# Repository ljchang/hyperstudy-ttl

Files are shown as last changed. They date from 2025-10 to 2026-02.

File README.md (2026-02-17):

# HyperStudy TTL

RP2040-based TTL pulse generator for HyperStudy experiments with electrical isolation via optocoupler.

## Architecture

```
HyperStudy TriggerComponent → hyperstudy-bridge → RP2040 (this firmware) → TTL Output
```

This repository contains the **RP2040 firmware** that receives trigger commands from [hyperstudy-bridge](https://github.com/cosanlab/hyperstudy-bridge) and generates electrically-isolated TTL pulses (configurable duration, default 10ms) for external equipment.

## Features

- **Fast & Reliable:** <1ms latency via USB serial communication
- **Electrical Isolation:** HCPL-2211 optocoupler protects both devices
- **Bridge Compatible:** Response format matches hyperstudy-bridge parser expectations
- **Easy Setup:** PlatformIO-based firmware with comprehensive installation docs

## Quick Start

### 1. Install Firmware

```bash
cd firmware
pio run --target upload
```

### 2. Test Connection

```bash
pio device monitor
```

Type `PULSE` and press Enter. The device should respond with `OK:Pulse sent`. Each device reports its unique serial number on startup.

### 3. Full Setup

See **[INSTALLATION.md](./INSTALLATION.md)** for complete instructions including:
- Hardware assembly and optocoupler wiring
- Bridge integration and configuration
- TriggerComponent setup in HyperStudy
- Troubleshooting guide

## Hardware

- **Microcontroller:** Adafruit Feather RP2040
- **Optocoupler:** HCPL-2211 (for isolation)
- **Pulse Output:** GPIO Pin 6 / D4 (configurable duration, default 10ms HIGH pulse)
- **Communication:** USB serial, 115200 baud
- **USB Identification:** VID: `0x239A`, PID: `0x80F1`

See [OPTOCOUPLER_WIRING.md](./OPTOCOUPLER_WIRING.md) for detailed wiring instructions.

## Commands

The firmware accepts case-insensitive serial commands:

| Command | Response | Description |
|---|---|---|
| `PULSE` | `OK:Pulse sent` | Triggers TTL pulse (default duration) |
| `PULSE <ms>` | `OK:Pulse sent` | Triggers TTL pulse with specified duration |
| `SETDURATION <ms>` | `OK:Duration set to <ms>ms` | Sets default pulse duration (1-10000ms) |
| `TIMING` | `OK:Timing us:<N>,dur:<ms>` | Reports last pulse timing (serial-to-GPIO, µs) |
| `TEST` | `OK:Test successful` | Connection validation |
| `VERSION` | `OK:Version 1.4.0` | Firmware version query |
| `SERIAL` | `OK:Serial <hex>` | Reports unique board serial number |
| `LONGPULSE` | `OK:Long pulse sent` | Triggers 3-second pulse for testing |

## Device Discovery

The device can be reliably found by USB VID/PID, regardless of which port macOS assigns:

```python
# Find device by VID/PID (works with any HyperStudy TTL device)
python3 testing/find_ttl_port.py
```

This returns the current port path (e.g., `/dev/cu.usbmodem2101`).

## Alternative Implementations

Alternative firmwares (Arduino IDE, CircuitPython) are provided in `/examples` for reference but are **not recommended** for production use as they may not be fully compatible with hyperstudy-bridge.

## Documentation

- **[INSTALLATION.md](./INSTALLATION.md)** - Complete setup guide with bridge integration
- **[OPTOCOUPLER_WIRING.md](./OPTOCOUPLER_WIRING.md)** - Detailed optocoupler wiring instructions
- **[CLAUDE.md](./CLAUDE.md)** - Developer notes and architecture details

## Support

For detailed user documentation on using TTL triggers in HyperStudy experiments, see the [HyperStudy documentation](https://github.com/cosanlab/hyperstudy).

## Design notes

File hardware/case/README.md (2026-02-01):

# HyperStudy TTL Case

3D printable enclosure for the HyperStudy TTL FeatherWing + Adafruit Feather RP2040 stack.

## Files

| File | Description |
|---|---|
| `hyperstudy-ttl-case.scad` | OpenSCAD parametric design source |
| `bottom.stl` | Bottom shell (generate from OpenSCAD) |
| `top.stl` | Top shell (generate from OpenSCAD) |

## Generating STL Files

1. Install [OpenSCAD](https://openscad.org/downloads.html)
2. Open `hyperstudy-ttl-case.scad`
3. For bottom shell:
   - Comment out assembly view at bottom
   - Uncomment `bottom_shell();`
   - Render (F6) and Export as STL
4. For top shell:
   - Comment out `bottom_shell();`
   - Uncomment `top_shell();`
   - Render (F6) and Export as STL

## Printing Recommendations

### Material
- **PLA**: Easy to print, good for most uses
- **PETG**: Better heat resistance and durability
- **ABS**: Best durability, requires enclosure

### Settings (Bambu Studio / PrusaSlicer)
| Parameter | Recommended | Notes |
|---|---|---|
| Layer height | 0.20mm | 0.16mm for finer detail |
| Walls | 4 perimeters | Strength at screw holes |
| Top/Bottom | 5 layers | Prevents flex |
| Infill | 15% gyroid | Good strength-to-weight |
| Supports | Not required | Designed for supportless printing |
| Brim | 5mm (first print) | Helps bed adhesion |

### Print Orientation (Critical)
- **Bottom shell**: Print as exported (floor on print bed)
- **Top shell**: Flip upside down in slicer (ceiling on print bed, open side facing up)

### Print Time (Bambu P1/X1 estimated)
- Bottom shell: ~45min - 1 hour
- Top shell: ~1 - 1.5 hours

## Hardware Required

| Item | Quantity | Notes |
|---|---|---|
| M2 x 35mm pan head screws | 4 | Through top shell, PCB, standoffs |
| M2 hex nuts | 4 | Press into hex pockets on bottom exterior |
| Rubber feet (optional) | 4 | ~10mm diameter adhesive feet |

## Assembly

1. **Prepare the PCB stack**
   - Solder all components to FeatherWing
   - Stack FeatherWing onto Feather RP2040 via headers

2. **Install M2 nuts in bottom shell**
   - Press M2 hex nuts into the 4 hex pockets on the exterior bottom
   - Nuts should sit flush or slightly recessed

3. **Install PCB in bottom shell**
   - Place assembled PCB stack onto the 4 standoffs
   - PCB mounting holes align with standoff holes
   - USB port aligns with cutout on short end
   - BNC connector faces opposite end

4. **Attach top shell**
   - Place top shell over assembly
   - Interlocking lip on bottom shell fits inside top shell cavity (3 sides)
   - BNC connector protrudes through cutout
   - Screw holes align at all 4 corners

5. **Secure with screws**
   - Insert M2x35mm screws through counterbored holes in top shell
   - Screws pass through: top shell ceiling > PCB > standoffs > floor > nuts
   - Tighten snugly (don't overtighten - plastic threads)

6. **Add rubber feet (optional)**
   - Apply adhesive rubber feet to bottom exterior

## Design Features

### Interlocking Lip
The bottom shell has a 1.5mm tall lip that extends into the top shell on three sides (USB end and both long sides). The BNC end is open to accommodate the panel-mount connector. This provides:
- Lateral alignment between shells
- Prevents shifting during use
- 0.3mm clearance for FDM printing tolerances

### PCB Support
The top shell includes internal ribs that press down on the PCB edges, securing it in place when assembled.

## Customization

The OpenSCAD file is fully parametric. Key parameters to adjust:

```scad
/* Fit adjustments */
pcb_clearance = 1.5;          // Clearance around PCB edges (mm)
lip_clearance = 0.3;          // Gap between interlocking lip and top shell (mm)

/* Structural */
wall = 2.5;                   // Wall thickness (mm)
floor_thickness = 6;          // Bottom shell floor (mm)
ceiling_thickness = 3.5;      // Top shell ceiling (mm)

/* Component clearance */
component_height_top = 19.6;  // Height above PCB for Feather + headers (mm)
component_height_bottom = 5;  // Height below PCB for BNC/solder joints (mm)

/* Connector cutouts */
bnc_diameter = 13;            // BNC hole diameter (mm)
usb_width = 10;               // USB-C port width (mm)
usb_height = 4;               // USB-C port height (mm)
```

## Dimensions

| Dimension | Value |
|---|---|
| Case length | ~93mm |
| Case width | ~43mm |
| Case height (assembled) | ~36mm |
| Bottom shell height | 11mm |
| Top shell height | 24.7mm |
| Wall thickness | 2.5mm |

## Troubleshooting

### Fit Issues
| Symptom | Likely Cause | Fix |
|---|---|-----|
| PCB won't seat flat | Standoffs too tall | Reduce `standoff_height` |
| Shells won't close | PCB sitting too high | Verify `standoff_height = component_height_bottom` |
| Top shell shifts laterally | Lip clearance too large | Reduce `lip_clearance` |
| Lip won't fit in top shell | Lip clearance too small | Increase `lip_clearance` to 0.4mm |
| USB cable won't insert | Cutout too small | Increase `usb_width` or `usb_height` |
| BNC nut won't thread | Hole too small | Increase `bnc_diameter` |

### Print Quality Issues
| Symptom | Likely Cause | Fix |
|---|---|-----|
| Stringing at cutouts | Retraction settings | Increase retraction, enable wipe |
| Hex pockets too tight | FDM shrinkage | Increase `nut_width` parameter |
| Screw holes too tight | FDM shrinkage | Increase `screw_hole_diameter` |
| Warped corners | Bed adhesion | Add brim, increase bed temp |

### Measurement Tips
1. Use calipers - don't eyeball tolerances
2. Measure printed parts - actual dimensions often differ from CAD by +/-0.2mm
3. Test fit components before final assembly
4. If holes are slightly tight, an M2 drill bit can clean them up

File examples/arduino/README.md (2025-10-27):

# Arduino IDE Example

This is an alternative firmware implementation using the Arduino IDE.

**Note:** This is provided as an example only. The **recommended** firmware is in `/firmware` (PlatformIO).

## Compatibility Notes

- Uses emoji in responses (not parsed by hyperstudy-bridge)
- Different pin logic than primary firmware
- Easier for beginners to modify without PlatformIO

## Usage

1. Open `arduino_sketch_hyperstudyttl.ino` in Arduino IDE
2. Install Adafruit TinyUSB library
3. Select "Adafruit Feather RP2040" board
4. Upload to device

## Limitations

- Response format not fully compatible with hyperstudy-bridge parsing
- May require bridge code modifications to work correctly

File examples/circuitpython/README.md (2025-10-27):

# CircuitPython Example

This is an alternative firmware implementation using CircuitPython.

**Note:** This is provided as an example only. The **recommended** firmware is in `/firmware` (PlatformIO).

## Compatibility Notes

- Python-based, no compilation needed
- Slower response time than C++ implementations
- Easier to debug and modify on-device
- Response format has extra space: `"OK: Pulse Triggered!\n"` (may not parse correctly in bridge)

## Usage

1. Install CircuitPython on your Feather RP2040
2. Copy `code.py` to the CIRCUITPY drive
3. Device will auto-restart with new code

## Configuration

You may need to create `settings.toml` on CIRCUITPY for WebUSB origin configuration:

```toml
CIRCUITPY_USB_VENDOR = 0x239A
CIRCUITPY_USB_PRODUCT = 0x80F1
```

## Limitations

- Response format not fully compatible with hyperstudy-bridge parsing
- Slightly higher latency than compiled C++ firmware
- Requires CircuitPython 9+ for WebUSB support

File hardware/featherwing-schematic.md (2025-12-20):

# HyperStudy TTL FeatherWing Schematic

This document describes the schematic design for a FeatherWing add-on board that provides electrically-isolated TTL output from an Adafruit Feather RP2040.

## Design Overview

The FeatherWing provides:
- HCPL-2211 optocoupler for galvanic isolation
- Isolated 5V power supply (B0505S-1W DC-DC isolator)
- BNC output connector for TTL signal
- All necessary bypass capacitors and current limiting resistors

## Schematic Block Diagram

```
┌─────────────────────────────────────────────────────────────────────────────┐
│                         HyperStudy TTL FeatherWing                          │
├─────────────────────────────────────────────────────────────────────────────┤
│                                                                             │
│   Feather                                                                   │
│   Header         Input Stage           Isolation          Output Stage     │
│                                                                             │
│   D4 (GP6) ──────[220Ω]──────┐                                             │
│                               │      HCPL-2211                              │
│                               ├─────┤2 (A)  8├───────────┬──── +5V ISO     │
│                               │     │        │           │                  │
│   GND ────────────────────────┴─────┤3 (K)  7├──[47Ω]────┼───► BNC+        │
│                                     │        │           │                  │
│                              NC ────┤1      6├── NC      │                  │
│                                     │        │           │                  │
│                              NC ────┤4      5├───────────┼──── GND ISO     │
│                                     └────────┘           │      │          │
│                                                   [0.1µF]│    [BNC-]       │
│                                                          │                  │
│                                                          └──────────────────┤
│   USB 5V ─────┬─────[0.1µF]─────┬─────────────────────────────────────────┤
│               │                 │         B0505S-1W                        │
│               │                 │        ┌─────────┐                       │
│               └─────────────────┼────────┤+Vin Vout+├───────► +5V ISO     │
│                                 │        │         │                       │
│   GND ──────────────────────────┼────────┤-Vin Vout-├───────► GND ISO     │
│                                 │        └─────────┘     │                 │
│                              [10µF]                   [10µF]               │
│                                 │                        │                 │
│                                GND                    GND ISO              │
│                                                                             │
└─────────────────────────────────────────────────────────────────────────────┘
```

## Component List

### Semiconductors
| Ref | Component | Value | Package | Notes |
|-----|---|---|---|---|
| U1 | HCPL-2211 | - | DIP-8 | Totem pole optocoupler |
| U2 | B0505S-1W | 5V→5V | SIP-4 | 1W isolated DC-DC converter |

### Resistors
| Ref | Value | Package | Tolerance | Notes |
|-----|---|---|---|---|
| R1 | 220Ω | 0805 | 5% | LED current limiting (8mA) |
| R2 | 47Ω | 0805 | 5% | BNC impedance matching |

### Capacitors
| Ref | Value | Package | Voltage | Notes |
|-----|---|---|---|---|
| C1 | 0.1µF | 0805 | 16V | DC isolator input filter |
| C2 | 10µF | Electrolytic | 16V | DC isolator input bulk |
| C3 | 0.1µF | 0805 | 16V | Optocoupler bypass (Pin 5-8) |
| C4 | 10µF | Electrolytic | 16V | Optocoupler output bulk |

### Connectors
| Ref | Component | Notes |
|-----|---|---|
| J1 | Feather Header (16-pin) | Left side of Feather |
| J2 | Feather Header (12-pin) | Right side of Feather |
| J3 | BNC Female | Panel mount or PCB mount |

## Feather Header Pinout (Relevant Pins)

### Left Header (J1 - 16 pins, top to bottom)
```
Pin  Name    Use
1    RST     -
2    3V3     -
3    AREF    -
4    GND     Optocoupler cathode (Pin 3)
5    A0      -
6    A1      -
7    A2      -
8    A3      -
9    24      -
10   25      -
11   SCK     -
12   MOSI    -
13   MISO    -
14   RX      -
15   TX      -
16   D4      → TTL Trigger (GP6)
```

### Right Header (J2 - 12 pins, top to bottom)
```
Pin  Name    Use
1    VBAT    -
2    EN      -
3    VBUS    USB 5V → DC isolator input
4    D13     -
5    D12     -
6    D11     -
7    D10     -
8    D9      -
9    D6      -
10   D5      -
11   SCL     -
12   SDA     -
```

## Schematic Connections

### Input Stage (Non-Isolated)
1. **D4 (GP6)** → R1 (220Ω) → U1 Pin 2 (Anode)
2. **GND** → U1 Pin 3 (Cathode)
3. **VBUS** → C1 (0.1µF) → GND
4. **VBUS** → C2 (10µF +) → GND
5. **VBUS** → U2 Pin 1 (+Vin)
6. **GND** → U2 Pin 2 (-Vin)

### Output Stage (Isolated)
1. **U2 Pin 4 (+Vout)** → U1 Pin 8 (VCC)
2. **U2 Pin 3 (-Vout)** → U1 Pin 5 (GND)
3. **U1 Pin 5** → C3 (0.1µF) → U1 Pin 8
4. **U1 Pin 5** → C4 (10µF -), C4 (+) → U1 Pin 8
5. **U1 Pin 7 (VO)** → R2 (47Ω) → J3 BNC Center
6. **U1 Pin 5 (GND)** → J3 BNC Shield
7. **U1 Pin 1, 4, 6** → NC (No Connection)

## Design Notes

### Isolation Barrier
- The dashed line in the block diagram represents the isolation barrier
- Input ground (Feather GND) and output ground (ISO GND) must be kept separate
- The B0505S-1W provides 1kV isolation between input and output

### Component Placement
- Place C3 (bypass cap) as close to U1 pins 5 and 8 as possible
- Keep the input stage components grouped on one side of the board
- Keep the output stage components grouped on the other side
- Maintain creepage distance across isolation barrier (min 2mm recommended)

### Totem Pole Output
- The HCPL-2211 has an active push-pull output
- No pull-up resistor is needed
- Output can source/sink ~25mA

### Signal Integrity
- R2 (47Ω) provides approximate 50Ω impedance matching for BNC cable
- Keep traces to BNC connector short and direct

## EasyEDA Import Instructions

1. Open EasyEDA (https://easyeda.com)
2. Create a new project: File → New → Project
3. Create a new schematic: File → New → Schematic
4. Import components from LCSC (EasyEDA's parts library):
   - Search for each component by part number
   - Add to schematic
5. Wire components according to the connections above
6. Convert to PCB: Design → Convert to PCB
7. Arrange components on the PCB
8. Route traces (auto-route or manual)
9. Add ground planes if desired
10. Run DRC (Design Rule Check)
11. Generate Gerber files for fabrication

## Bill of Materials (BOM)

| Qty | Component | Value | LCSC Part # | Notes |
|-----|---|---|---|---|
| 1 | HCPL-2211 | - | C6933 | DIP-8 optocoupler |
| 1 | B0505S-1W | 5V | C87025 | DC-DC isolator |
| 1 | Resistor | 220Ω | C17557 | 0805, 5% |
| 1 | Resistor | 47Ω | C17714 | 0805, 5% |
| 2 | Capacitor | 0.1µF | C49678 | 0805 ceramic |
| 2 | Capacitor | 10µF | C19702 | Electrolytic 16V |
| 1 | BNC Connector | Female | C496553 | PCB mount |
| 1 | Pin Header | 1x16 2.54mm | C2337 | Female for Feather |
| 1 | Pin Header | 1x12 2.54mm | C2334 | Female for Feather |

Note: LCSC part numbers are examples. Verify availability and specifications before ordering.

## FeatherWing Dimensions

Standard FeatherWing dimensions:
- Width: 22.86mm (0.9")
- Length: 50.8mm (2.0")
- Mounting holes: Match Feather pattern

The BNC connector will extend beyond the standard FeatherWing footprint.
Consider using a right-angle BNC or panel-mount BNC with wires.

## Testing After Assembly

1. Power on with Feather RP2040 attached
2. Measure isolated 5V output (should read 4.1-5.0V)
3. Connect multimeter to BNC output
4. Idle voltage should be ~0.3V (LOW)
5. Send PULSE command via serial
6. Pulse voltage should reach ~3.9V (HIGH)

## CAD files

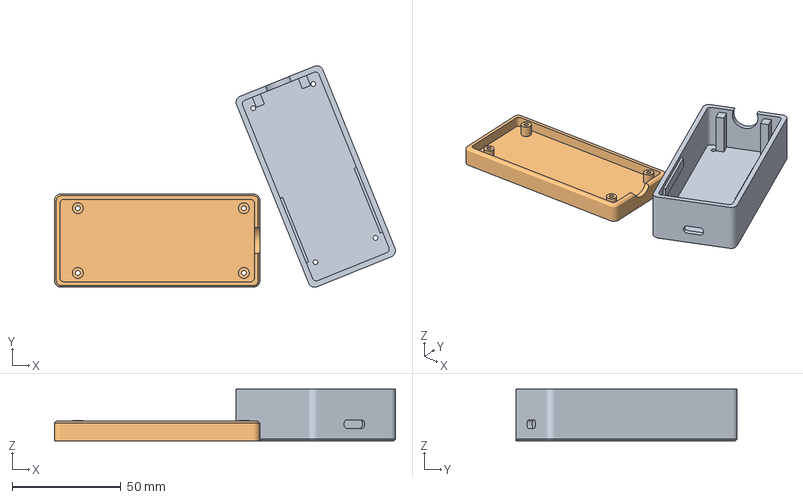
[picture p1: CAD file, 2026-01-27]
hardware/case/hyperstudy-ttl-case.3mf
156.5 x 101.7 x 23.7 mm
hyperstudy-ttl-case.stl_2
hyperstudy-ttl-case.stl_1

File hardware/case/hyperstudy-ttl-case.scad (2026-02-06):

// HyperStudy TTL FeatherWing Case
// Parametric design for 3D printing
//
// Usage:
//   - Render bottom_shell() and export as bottom.stl
//   - Render top_shell() and export as top.stl
//   - Print orientation (IMPORTANT):
//       * Bottom shell: Print as exported (floor on bed)
//       * Top shell: FLIP UPSIDE DOWN in slicer (ceiling on bed, open side up)
//   - Insert M2 nuts into hex pockets on bottom shell exterior
//   - Assemble with 4x M2x35mm pan head screws through top shell, PCB, standoffs, into nuts

/* [PCB Dimensions] */
// FeatherWing v1.1 PCB length (mm)
pcb_length = 81.30;
// FeatherWing v1.1 PCB width (mm)
pcb_width = 34.80;
// PCB thickness (mm)
pcb_thickness = 1.6;
// BNC connector extension past board edge (mm) - set to 0 so BNC protrudes outside case
bnc_extension = 0;
// Feather overhang past FeatherWing on USB end (mm)
feather_extension = 3.5;

/* [Component Heights] */
// Height above FeatherWing PCB for Feather RP2040 + headers (measured: 19.6mm to top)
component_height_top = 19.6;
// Height below FeatherWing PCB for BNC/solder joints (measured: 4.75mm lowest point)
component_height_bottom = 5;

/* [Case Parameters] */
// Wall thickness (mm)
wall = 2.5;
// Floor thickness (mm) - 7mm for solid bridging over nut pockets (4.5mm solid above pocket)
floor_thickness = 7;
// Top shell ceiling thickness (mm) - needs enough material for counterbore + shaft shelf
// For M2 pan head: 2mm counterbore + 2.5mm shelf = 4.5mm minimum
ceiling_thickness = 4.5;
// PCB clearance on each side (mm) - increased to accommodate support ribs
pcb_clearance = 1.5;
// Corner radius (mm)
corner_radius = 3;
// External edge chamfer for clean printing (mm)
edge_chamfer = 0.8;

/* [Screw Parameters] */
// M2 screw clearance hole diameter (mm) - oversized for FDM shrinkage
screw_hole_diameter = 2.6;
// M2 nut width across flats (mm) - actual is 4.0mm, add 0.7mm for FDM shrinkage
nut_width = 4.7;
// M2 nut pocket depth (mm) - actual nut is 1.6mm, extra depth for capture and clearance
nut_pocket_depth = 2.5;
// M2 pan head counterbore diameter (mm) - head is ~4mm, add tolerance
counterbore_diameter = 4.5;
// M2 pan head counterbore depth (mm) - head is ~2mm, flush fit
counterbore_depth = 2.0;

/* [Connector Cutouts] */
// USB-C port width (mm)
usb_width = 10;
// USB-C port height (mm)
usb_height = 4;
// USB-C corner radius for printability and aesthetics (mm)
usb_corner_radius = 1.5;
// USB port vertical offset from shell interface (mm) - adjusted +4.2mm from original calibration
usb_offset_z = 14.05;
// USB port horizontal offset from center (mm)
usb_offset_y = 0;
// BNC connector diameter (mm) - panel-mount requires ~12.5mm clearance (+0.5mm tolerance)
bnc_diameter = 13;
// BNC connector vertical offset from shell interface (mm) - positive moves hole up
bnc_offset_z = 2.65;

/* [PCB Support Ribs] */
// Enable PCB edge support ribs in top shell
pcb_supports_enabled = true;
// Rib width (mm) - extends from wall over PCB edge, pressing down on PCB surface
pcb_support_width = 4;
// Ribs extend from pcb_rail_z_offset to ceiling (matching BNC corner posts)

// Rail positioning - runs along Feather section only (avoids FeatherWing components)
// Start after USB-side screw holes, run along where Feather sits
pcb_rail_start = 12;              // Start X position (mm from USB end wall, after screw holes)
pcb_rail_length = 32;             // Length of rail (mm) - covers Feather area
// Z offset = PCB thickness + clearance, so rails are above PCB when it sits flush/inset
pcb_rail_z_offset = pcb_thickness + 0.5;  // 1.6 + 0.5 = 2.1mm from open edge

// BNC-side corner posts (between BNC cutout and screw holes)
bnc_posts_enabled = true;
bnc_post_diameter = 4;            // Post diameter (mm)
bnc_post_height = 4;              // Post height (mm)
bnc_post_inset_x = 5;             // Post X inset from BNC end wall (mm)
bnc_post_inset_y = 10;            // Post Y inset from case side walls (mm)

/* [Logo] */
// Logo scale factor (0.07 = large, may extend to edges)
logo_scale = 0.07;
// Logo emboss depth (mm)
logo_depth = 0.8;
// Logo X offset from center (mm)
logo_offset_x = 0;
// Logo Y offset from center (mm)
logo_offset_y = 22;
// Logo rotation (degrees)
logo_rotation = 90;

/* [Rendering] */
// Resolution for curved surfaces
$fn = 50;

// Calculated dimensions
case_inner_length = pcb_length + 2 * pcb_clearance + feather_extension;
case_inner_width = pcb_width + 2 * pcb_clearance;
case_outer_length = case_inner_length + 2 * wall;
case_outer_width = case_inner_width + 2 * wall;
case_height_bottom = component_height_bottom + floor_thickness;
case_height_top = component_height_top + ceiling_thickness + pcb_thickness;
total_case_length = case_outer_length + bnc_extension;

// PCB ledge parameters
pcb_ledge_height = 2;
pcb_ledge_width = 1.5;

// FeatherWing v1.1 mounting hole positions (from PCB corner)
// 4x M2 mounting holes extracted from Gerber drill file
fw_hole_inset_x = 2.54;           // Hole inset from left/right edges
fw_hole_inset_y = 2.54;           // Hole inset from bottom/top edges
fw_hole_spacing_x = 76.2;         // Horizontal spacing between holes
fw_hole_spacing_y = 29.72;        // Vertical spacing between holes
fw_hole_diameter = 2.032;         // M2 clearance holes in PCB

// Standoff parameters (sized for M2 screws)
standoff_diameter = 5;
standoff_hole_diameter = 2.6;     // M2 clearance hole - oversized for FDM shrinkage
standoff_height = component_height_bottom;  // Height to support PCB at shell interface
pcb_bnc_offset = 0.8;             // Extra clearance between PCB/standoffs and BNC end (mm)

/* [Shell Interlocking] */
// Lip height extending above bottom shell edge (mm)
// Must be less than pcb_rail_z_offset to clear top shell support ribs
lip_height = 1.5;
// Lip wall thickness (mm) - reduced from 1.5 to provide 0.3mm clearance to PCB edge
lip_thickness = 1.2;
// Clearance between lip and top shell inner wall (mm)
lip_clearance = 0.3;

// Module: Interlocking lip for bottom shell (excludes BNC end)
// Creates a thin wall rising from the inner perimeter to fit inside top shell
module interlocking_lip() {
    // Inner dimensions where lip attaches (flush with cavity wall for printability)
    // lip_clearance is applied to the TOP shell's cavity, not here
    inner_x_start = wall;
    inner_x_end = wall + case_inner_length - lip_clearance;  // Stop before BNC extension
    inner_y_start = wall;
    inner_y_end = wall + case_inner_width;
    inner_radius = corner_radius - wall/2;

    // Lip rises from top of bottom shell
    translate([0, 0, case_height_bottom]) {
        difference() {
            // Outer boundary of lip (flush with cavity walls for printability)
            hull() {
                for (x = [inner_x_start + inner_radius, inner_x_end - inner_radius]) {
                    for (y = [inner_y_start + inner_radius, inner_y_end - inner_radius]) {
                        translate([x, y, 0])
                            cylinder(r = inner_radius, h = lip_height);
                    }
                }
            }

            // Inner cutout (lip_thickness inward from outer boundary)
            translate([0, 0, -0.1])
            hull() {
                for (x = [inner_x_start + inner_radius + lip_thickness, inner_x_end - inner_radius - lip_thickness]) {
                    for (y = [inner_y_start + inner_radius + lip_thickness, inner_y_end - inner_radius - lip_thickness]) {
                        translate([x, y, 0])
                            cylinder(r = inner_radius, h = lip_height + 0.2);
                    }
                }
            }

            // Cut off BNC end - remove lip from BNC wall area
            // Cut starts where the main case inner length ends (before BNC extension)
            translate([inner_x_end - inner_radius - 1, -1, -0.1])
                cube([inner_radius + bnc_extension + wall + 2, case_outer_width + 2, lip_height + 0.2]);
        }
    }
}

// Module: Rounded box with optional edge chamfer
module rounded_box(length, width, height, radius, chamfer = 0) {
    if (chamfer > 0) {
        // Box with chamfered top edge for clean printing
        hull() {
            for (x = [radius, length - radius]) {
                for (y = [radius, width - radius]) {
                    translate([x, y, 0])
                        cylinder(r = radius, h = height - chamfer);
                    translate([x, y, height - chamfer])
                        cylinder(r1 = radius, r2 = radius - chamfer, h = chamfer);
                }
            }
        }
    } else {
        // Simple rounded box without chamfer
        hull() {
            for (x = [radius, length - radius]) {
                for (y = [radius, width - radius]) {
                    translate([x, y, 0])
                        cylinder(r = radius, h = height);
                }
            }
        }
    }
}
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

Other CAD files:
hardware/case/hyperstudy-ttl-case.stl

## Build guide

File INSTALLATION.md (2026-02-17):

# HyperStudy TTL Installation Guide

Complete setup guide for the RP2040 TTL trigger device used with HyperStudy experiments.

## Architecture Overview

```
HyperStudy TriggerComponent → hyperstudy-bridge → RP2040 (this device) → TTL Output
```

**Data Flow:**
1. **TriggerComponent** (in HyperStudy experiment) sends trigger request
2. **hyperstudy-bridge** receives request via WebSocket and forwards to RP2040 via USB serial
3. **RP2040** (this firmware) sends TTL pulse on GPIO Pin 6 (D4) with configurable duration (default 10ms)
4. **Optocoupler** (HCPL-2211) provides electrical isolation to external equipment

## Hardware Requirements

- **Adafruit Feather RP2040** microcontroller
- **HCPL-2211** optocoupler (for electrical isolation)
- **330Ω resistor** (for LED current limiting)
- **0.1 µF capacitor** (decoupling)
- Breadboard and jumper wires
- BNC cable (for TTL output)
- USB-C cable

## Part 1: Hardware Assembly

### Wiring the Optocoupler

See [OPTOCOUPLER_WIRING.md](./OPTOCOUPLER_WIRING.md) for detailed wiring instructions.

**Quick Reference:**
```
Feather GPIO Pin 5 → 330Ω resistor → HCPL-2211 Pin 2 (Anode)
HCPL-2211 Pin 3 (Cathode) → Feather GND
HCPL-2211 Pin 8 (Vcc) → 5V (from Feather USB pin)
HCPL-2211 Pin 5 (GND) → Isolated GND rail (separate from Feather GND!)
HCPL-2211 Pin 6 (Output) → BNC center pin
BNC shield → Isolated GND rail
```

**Critical:** Input and output grounds must be separate for electrical isolation!

### Signal Behavior

- **Idle state:** GPIO Pin 5 = LOW (0V) → TTL Output = LOW
- **Pulse active:** GPIO Pin 5 = HIGH (3.3V) → TTL Output = HIGH (5V after optocoupler)
- **Pulse duration:** 10 milliseconds (configurable in firmware)

## Part 2: Firmware Installation

### Prerequisites

Install PlatformIO:
- **VS Code:** Install PlatformIO IDE extension
- **Command line:** `pip install platformio`

### Flash the Firmware

1. **Connect the Feather RP2040** to your computer via USB-C

2. **Navigate to firmware directory:**
   ```bash
   cd firmware
   ```

3. **Build and upload:**
   ```bash
   pio run --target upload
   ```

4. **Verify installation:**
   The device should appear as a USB serial port and display:
   ```
   RP2040 TTL Trigger Ready
   Firmware Version: 1.4.0
   Serial: <unique hex ID>
   Trigger Pin: GP6
   Default Pulse Duration: 10ms
   Commands: PULSE [ms], SETDURATION <ms>, TIMING, TEST, VERSION, SERIAL
   ```

### Test the Firmware

Open a serial monitor to test:

```bash
pio device monitor
```

**Test commands:**
- `PULSE` or `pulse` → Triggers TTL pulse (default 10ms), responds with `OK:Pulse sent`
- `PULSE 5` → Triggers 5ms TTL pulse, responds with `OK:Pulse sent`
- `SETDURATION 20` → Sets default pulse duration to 20ms
- `TIMING` → Reports last pulse timing (serial-to-GPIO latency in µs)
- `TEST` or `test` → Connection test, responds with `OK:Test successful`
- `VERSION` → Returns firmware version, responds with `OK:Version 1.4.0`
- `SERIAL` → Reports unique board serial number

**Expected behavior:** GPIO Pin 6 (D4) LED should flash briefly when you send `PULSE`.

## Part 3: Integration with hyperstudy-bridge

### Device Discovery

The HyperStudy TTL device can be reliably identified by USB VID/PID:
- **Vendor ID (VID):** `0x239A` (9242 decimal)
- **Product ID (PID):** `0x80F1` (32497 decimal)

This allows the bridge to find the device automatically, even when macOS assigns different port numbers (e.g., `/dev/cu.usbmodem101` vs `/dev/cu.usbmodem2101`).

### Bridge Configuration

**Option 1: Auto-discovery (Recommended)**

Use the provided Python script to find the device:

```bash
python3 /path/to/hyperstudy-ttl/testing/find_ttl_port.py
```

This returns the current port path, which can be used by the bridge.

**Option 2: Manual port identification**

   **macOS:**
   ```bash
   # Use cu.* ports for outgoing serial communication
   ls /dev/cu.usb*
   # Example: /dev/cu.usbmodem2101
   ```

   **Linux:**
   ```bash
   ls /dev/ttyACM*
   # Example: /dev/ttyACM0
   ```

   **Windows:**
   ```bash
   # Check Device Manager → Ports (COM & LPT)
   # Example: COM3
   ```

**Configure the bridge:**

In your `hyperstudy-bridge` application, configure the TTL device with either:
- Device discovery by VID/PID (preferred)
- The specific serial port path

**Test the bridge connection:**

The bridge should connect to the RP2040 and be able to send pulse commands.

### Communication Protocol

The firmware expects commands via USB serial (115200 baud):

**Command format:** `COMMAND\n` (newline-terminated, case-insensitive)

**Bridge-compatible responses:**
- Success: `OK:Message`
- Error: `ERROR:Message`

### HyperStudy TriggerComponent Integration

In your HyperStudy experiment configuration:

1. Configure a **TriggerComponent** with mode set to use the bridge
2. The TriggerComponent will communicate with `hyperstudy-bridge` via WebSocket (port 9000)
3. The bridge forwards the trigger to this RP2040 device via USB serial
4. The RP2040 sends the TTL pulse

**Latency:** Typical round-trip latency is <1ms for scientific timing accuracy.

## Part 4: Troubleshooting

### Device Not Detected

**Symptom:** Serial port doesn't appear

**Solutions:**
- Reconnect USB cable
- Try different USB port
- Check that Feather RP2040 is powered (LED should be on)
- On Linux: Check permissions (`sudo chmod 666 /dev/ttyACM0`)

### Bridge Can't Connect

**Symptom:** Bridge shows connection timeout

**Solutions:**
- Verify correct serial port in bridge configuration
- Close other applications using the serial port (Arduino IDE, serial monitors, etc.)
- Restart the bridge application
- Reflash the firmware

### No TTL Output

**Symptom:** Device responds to commands but no output on BNC

**Solutions:**
- Verify optocoupler wiring (see OPTOCOUPLER_WIRING.md)
- Test with multimeter: Pin 5 should go HIGH (3.3V) during pulse
- Check isolated power supply (5V on HCPL Pin 8)
- Verify 330Ω resistor is in place
- Check BNC cable connection

### High Latency (>1ms)

**Symptom:** Bridge reports latency warnings

**Solutions:**
- Close other USB devices and applications
- Use USB 2.0 port (sometimes more stable than USB 3.0)
- Check for USB hub issues (connect directly to computer)
- Verify 115200 baud rate is configured correctly

### Commands Not Recognized

**Symptom:** Device responds with `ERROR:Unknown command`

**Solutions:**
- Verify newline-terminated commands (`PULSE\n`)
- Check for extra whitespace or special characters
- Confirm firmware version supports the command (`VERSION`)
- Reflash firmware if responses are garbled

## Part 5: Testing Scripts

Python scripts are provided in `/testing` for device validation:

```bash
# Detect RP2040 on serial ports
python testing/detect_device.py

# Send test pulse and measure latency
python testing/test_pulse.py

# Validate bridge connection
python testing/validate_bridge.py
```

## Advanced Configuration

### Changing Pulse Duration

Pulse duration can be configured at runtime without reflashing:

**Via serial command (temporary, until reboot):**
```
SETDURATION 20
```

**Via inline parameter (per-pulse):**
```
PULSE 20
```

**Via hyperstudy-bridge:** Configure `pulse_duration_ms` in the TTL device settings. The bridge sends the duration with each PULSE command.

**Permanently (in firmware):** Edit `firmware/src/main.cpp`:
```cpp
#define DEFAULT_PULSE_DURATION_MS 10  // Change default duration in milliseconds
```
Then rebuild and upload: `cd firmware && pio run --target upload`

### Using Alternative Firmware

See `/examples` directory for Arduino IDE and CircuitPython implementations.

**Note:** Alternative firmwares may not be fully compatible with hyperstudy-bridge response parsing.

## Support

For issues specific to:
- **This firmware:** Open issue in this repository
- **Bridge integration:** See hyperstudy-bridge documentation
- **HyperStudy experiments:** See HyperStudy documentation

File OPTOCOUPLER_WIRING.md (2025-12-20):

# HCPL-2211 Optocoupler Wiring Guide

## HCPL-2211 Pinout (from datasheet)

```
        ┌───∪───┐
NC ─────┤1     8├───── VCC (4.5-20V)
ANODE ──┤2     7├───── VO (Output)
CATHODE─┤3     6├───── NC
NC ─────┤4     5├───── GND
        └───────┘
```

**Key features:**
- Totem pole output (no pull-up resistor needed)
- Non-inverting: LED ON = Output HIGH, LED OFF = Output LOW
- Wide VCC range: 4.5V to 20V

## Circuit Diagram

```
Feather RP2040 Side                     Isolated Output Side

                    HCPL-2211                    DC Isolator
                   ┌─────────┐                  ┌─────────┐
        NC ────────┤1      8 ├──────────────────┤ +Out    │
                   │         │       │          │         │
GPIO 6 ──[220Ω]───┤2 (A)  7 ├──[47Ω]──► BNC+   │  5V     │
                   │         │                  │ Isolated│
Feather GND ──────┤3 (K)  6 ├── NC             │         │
                   │         │                  │         │
        NC ────────┤4      5 ├──────────────────┤ -Out    ├──► BNC-
                   └─────────┘       │          └─────────┘
                                     │               │
                              [0.1µF ceramic]   [0.1µF cer]
                              [10µF electro]    (on input)
                                     │               │
                                    GND            GND

Legend:
- A = Anode (LED +)
- K = Cathode (LED -)
- [220Ω] = Input current limiting resistor
- [47Ω] = Output series resistor (impedance matching)
- [0.1µF] = Ceramic bypass capacitor
- [10µF] = Electrolytic bulk capacitor
```

## Component Values

### Input Side

1. **R1 (LED Current Limiting): 220Ω**
   - Calculation: (3.3V - 1.5V) / 220Ω ≈ 8mA
   - Provides fast switching response
   - Within safe operating range for pulsed operation

### Output Side

2. **R2 (Series Output Resistor): 47Ω**
   - Impedance matching for BNC cable (50Ω nominal)
   - Optional but recommended for signal integrity

3. **C1 (Bypass Capacitor): 0.1µF ceramic**
   - Required per datasheet (between Pin 5 and Pin 8)
   - Filters high-frequency noise

4. **C2 (Bulk Capacitor): 10-100µF electrolytic**
   - On DC isolator output
   - Provides stable power during switching
   - Smooths voltage ripple

### DC Isolator Input

5. **C3 (Input Filter): 0.1µF ceramic**
   - Filters noise from USB power

## Step-by-Step Wiring

### Input Side (Feather Connection):
1. Connect GPIO Pin 6 (D4) to one end of the 220Ω resistor
2. Connect other end of resistor to **Pin 2** of HCPL-2211 (Anode)
3. Connect **Pin 3** of HCPL-2211 (Cathode) to Feather GND

### Output Side (Isolated TTL):
1. Connect DC isolator positive output to **Pin 8** (VCC)
2. Connect DC isolator negative output to **Pin 5** (GND)
3. Connect 0.1µF ceramic capacitor between Pin 5 and Pin 8
4. Connect 10µF electrolytic capacitor across DC isolator output (+ to +, - to -)
5. Connect **Pin 7** (VO) to one end of 47Ω resistor
6. Connect other end of 47Ω resistor to BNC center pin (+)
7. Connect **Pin 5** (GND) to BNC shield (-)
8. Leave Pin 6 unconnected (NC)

### DC Isolator Input:
1. Connect USB 5V to DC isolator input positive
2. Connect Feather GND to DC isolator input negative
3. Add 0.1µF ceramic capacitor across input

## Signal Behavior

### Truth Table (Non-Inverting)
| GPIO State | LED State | Output (VO) |
|---|---|---|
| LOW | OFF | LOW (~0.3V) |
| HIGH | ON | HIGH (~3.9V)|

### Firmware Logic (OFF-to-ON pulses)
- **Idle**: GPIO LOW → LED OFF → Output LOW (~280mV)
- **Pulse**: GPIO HIGH → LED ON → Output HIGH (~3.9V)

### Timing
- Propagation delay: ~150-300ns typical
- Rise/fall time: ~30ns / ~7ns typical
- Suitable for scientific timing (<1ms latency requirement)

## Important Notes

### Isolation
- The optocoupler provides electrical isolation between the Feather and your TTL device
- Keep grounds separate: Feather GND ≠ DC Isolator output GND
- This protects both devices from ground loops and voltage spikes

### Power Requirements
- Input side: Powered by Feather (3.3V logic)
- Output side: Requires isolated 5V supply (DC isolator)
- Output current: Totem pole can source/sink ~25mA

### No Pull-up Resistor Needed
- The HCPL-2211 has a totem pole (push-pull) output
- It actively drives both HIGH and LOW states
- Do NOT add a pull-up resistor

### Output Voltage
- VOH ≈ VCC - 0.3V (with totem pole)
- With 4.1V supply: expect ~3.8-3.9V output
- This is valid TTL level (>2.0V = HIGH)

## Troubleshooting

**No output signal:**
- Verify DC isolator is providing power to Pin 8
- Check 0.1µF bypass capacitor is installed
- Confirm LED is conducting (measure ~1.4V at Pin 2 relative to Pin 3)

**Output stuck HIGH:**
- Check GPIO is actually going LOW at idle
- Verify Pin 3 (Cathode) connects to Feather GND, not Pin 2

**Output stuck LOW:**
- Check DC isolator output voltage (should be 4-5V)
- Verify Pin 2 (Anode) receives the resistor, not Pin 1 or Pin 3

**Weak or noisy signal:**
- Add/verify 10µF electrolytic on DC isolator output
- Check all ground connections are solid

## Parts List

| Component | Value | Quantity | Notes |
|---|---|---|---|
| HCPL-2211 | - | 1 | DIP-8 optocoupler |
| Resistor | 220Ω | 1 | 1/4W, input current limiting |
| Resistor | 47Ω | 1 | 1/4W, output impedance matching |
| Capacitor | 0.1µF ceramic | 2 | Bypass/filter |
| Capacitor | 10µF electrolytic | 1 | 10V+ rating, bulk filter |
| DC Isolator | 5V isolated | 1 | e.g., B0505S-1W or similar |
| BNC Connector | - | 1 | Panel mount or cable |

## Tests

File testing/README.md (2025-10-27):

# Testing Scripts

Python scripts for validating RP2040 TTL device functionality and bridge compatibility.

## Requirements

```bash
pip install pyserial
```

## Scripts

### 1. detect_device.py

Automatically scans serial ports to find the RP2040 TTL device.

**Usage:**
```bash
python detect_device.py
```

**Features:**
- Auto-detects Feather RP2040 devices
- Verifies firmware version
- Runs basic connection tests
- Reports device information

### 2. test_pulse.py

Measures TTL pulse latency by sending multiple PULSE commands and collecting statistics.

**Usage:**
```bash
# Auto-detect device
python test_pulse.py

# Specify port manually
python test_pulse.py --port /dev/ttyACM0

# Custom number of pulses
python test_pulse.py --num-pulses 100

# Custom interval between pulses
python test_pulse.py --interval 0.5
```

**Output:**
- Individual pulse latencies
- Statistical summary (mean, median, min, max, std dev)
- Performance assessment

**Warning:** This script triggers actual TTL pulses. Ensure no sensitive equipment is connected unless you intend to trigger it.

### 3. validate_bridge.py

Validates that the device is compatible with hyperstudy-bridge by testing the exact protocol the bridge uses.

**Usage:**
```bash
# Auto-detect device
python validate_bridge.py

# Specify port manually
python validate_bridge.py --port /dev/ttyACM0
```

**Tests:**
- Exact command format bridge uses (`b"PULSE\n"`)
- Response format parsing (`"OK:Pulse sent"`)
- Case insensitivity (accepts both "PULSE" and "pulse")
- TEST command support
- Error handling

## Typical Workflow

1. **First time setup:**
   ```bash
   python detect_device.py
   ```
   This will find your device and verify the firmware is loaded.

2. **Test latency performance:**
   ```bash
   python test_pulse.py --num-pulses 20
   ```
   This ensures latency is acceptable (<1ms for scientific accuracy).

3. **Validate bridge compatibility:**
   ```bash
   python validate_bridge.py
   ```
   This confirms the device will work with hyperstudy-bridge.

## Troubleshooting

### Permission Denied (Linux)

```bash
sudo chmod 666 /dev/ttyACM0
```

Or add yourself to the `dialout` group:
```bash
sudo usermod -a -G dialout $USER
# Then log out and back in
```

### Device Not Found

1. Verify RP2040 is connected via USB
2. Check that firmware is flashed (see INSTALLATION.md)
3. Try a different USB cable or port
4. On Windows, check Device Manager for COM port

### High Latency

- Use USB 2.0 port instead of USB 3.0
- Connect directly to computer (not via hub)
- Close other USB-intensive applications
- Try a different USB cable

## Example Output

```
$ python validate_bridge.py

============================================================
HyperStudy Bridge Compatibility Validator
============================================================

Found device on /dev/ttyACM0
Device port: /dev/ttyACM0
Firmware version: 1.0.0

Validating bridge protocol compatibility...
------------------------------------------------------------

Test 1: Bridge PULSE command format
  Command: b'PULSE\n'
  Response: 'OK:Pulse sent'
  Latency: 0.87 ms
  ✓ PASS - Response format matches bridge expectations

...

============================================================
VALIDATION RESULTS
============================================================
✓ ALL TESTS PASSED

This device is compatible with hyperstudy-bridge.
```

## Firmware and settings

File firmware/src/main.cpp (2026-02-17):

#include <Arduino.h>
#include <Adafruit_TinyUSB.h>
#include <pico/unique_id.h>

// Configuration
#define TRIGGER_PIN 6  // D4 pin on Feather RP2040 = GP06
#define DEFAULT_PULSE_DURATION_MS 10
#define MAX_PULSE_DURATION_MS 10000

// Firmware version for device identification
#define FIRMWARE_VERSION "1.4.0"

// Board unique serial number (populated from flash chip ID in setup)
static char board_serial[2 * PICO_UNIQUE_BOARD_ID_SIZE_BYTES + 1];

// Configurable default pulse duration (settable via SETDURATION command)
static int pulse_duration_ms = DEFAULT_PULSE_DURATION_MS;

// Last pulse timing (microseconds from serial-available to GPIO toggle)
static unsigned long last_pulse_timing_us = 0;

void setup() {
  // Read unique board ID from flash chip (each RP2040 board has a unique ID)
  pico_get_unique_board_id_string(board_serial, sizeof(board_serial));

  // Initialize trigger pin for OFF-to-ON pulse behavior
  // HCPL-2211 has totem pole output (non-inverting, no pull-up needed):
  // GPIO LOW -> LED OFF -> Output LOW (idle state)
  // GPIO HIGH -> LED ON -> Output HIGH (pulse active)
  pinMode(TRIGGER_PIN, OUTPUT);
  digitalWrite(TRIGGER_PIN, LOW);  // Start with LED OFF (output LOW/idle)

  // Initialize USB Serial (compatible with hyperstudy-bridge)
  // USB serial descriptor is auto-generated from flash unique ID by TinyUSB
  Serial.begin(115200);

  // Wait briefly for USB connection
  while (!Serial && millis() < 5000) {
    delay(10);
  }

  Serial.println("RP2040 TTL Trigger Ready");
  Serial.print("Firmware Version: ");
  Serial.println(FIRMWARE_VERSION);
  Serial.print("Serial: ");
  Serial.println(board_serial);
  Serial.print("Trigger Pin: GP");
  Serial.println(TRIGGER_PIN);
  Serial.print("Default Pulse Duration: ");
  Serial.print(DEFAULT_PULSE_DURATION_MS);
  Serial.println("ms");
  Serial.println("Commands: PULSE [ms], SETDURATION <ms>, TIMING, TEST, VERSION, SERIAL");
}

void loop() {
  if (Serial.available() > 0) {
    unsigned long t_available = micros();
    String cmd = Serial.readStringUntil('\n');
    cmd.trim();
    cmd.toUpperCase();  // Accept case-insensitive commands

    if (cmd == "PULSE" || cmd.startsWith("PULSE ")) {
      // CRITICAL PATH: Toggle GPIO as fast as possible
      digitalWrite(TRIGGER_PIN, HIGH);
      last_pulse_timing_us = micros() - t_available;

      // Parse optional inline duration AFTER GPIO is already HIGH (not latency-critical)
      int duration = pulse_duration_ms;
      if (cmd.length() > 6) {
        int parsed = cmd.substring(6).toInt();
        if (parsed > 0 && parsed <= MAX_PULSE_DURATION_MS) {
          duration = parsed;
        }
      }

      delay(duration);
      digitalWrite(TRIGGER_PIN, LOW);  // Return to idle (output LOW)

      Serial.println("OK:Pulse sent");

    } else if (cmd.startsWith("SETDURATION ")) {
      // Configure default pulse duration (used when PULSE has no inline parameter)
      int parsed = cmd.substring(12).toInt();
      if (parsed > 0 && parsed <= MAX_PULSE_DURATION_MS) {
        pulse_duration_ms = parsed;
        Serial.print("OK:Duration set to ");
        Serial.print(pulse_duration_ms);
        Serial.println("ms");
      } else {
        Serial.print("ERROR:Invalid duration. Range: 1-");
        Serial.print(MAX_PULSE_DURATION_MS);
        Serial.println("ms");
      }

    } else if (cmd == "TIMING") {
      // Report last pulse timing (microseconds from serial-available to GPIO toggle)
      Serial.print("OK:Timing us:");
      Serial.print(last_pulse_timing_us);
      Serial.print(",dur:");
      Serial.println(pulse_duration_ms);

    } else if (cmd == "LONGPULSE") {
      // Long pulse for testing/visibility (3 seconds)
      digitalWrite(TRIGGER_PIN, HIGH);
      delay(3000);
      digitalWrite(TRIGGER_PIN, LOW);  // Return to idle (output LOW)
      Serial.println("OK:Long pulse sent");

    } else if (cmd == "TEST") {
      // Test command for connection validation
      Serial.println("OK:Test successful");

    } else if (cmd == "VERSION") {
      // Version query for device identification
      Serial.print("OK:Version ");
      Serial.println(FIRMWARE_VERSION);

    } else if (cmd == "SERIAL") {
      // Report unique board serial number
      Serial.print("OK:Serial ");
      Serial.println(board_serial);

    } else if (cmd != "") {
      Serial.print("ERROR:Unknown command: ");
      Serial.println(cmd);
    }
  }
  // No delay — tight polling for minimum latency.
  // RP2040 is a dedicated device with nothing else to do.
  // USB serial buffer is filled by interrupts regardless of loop timing.
}

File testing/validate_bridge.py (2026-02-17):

#!/usr/bin/env python3
"""
HyperStudy Bridge Connection Validator

Validates that the RP2040 TTL device is compatible with hyperstudy-bridge
by testing the exact command format and response parsing that the bridge uses.
"""

import serial
import time
import sys
import argparse


def validate_bridge_protocol(port):
    """
    Test the exact protocol used by hyperstudy-bridge.

    The bridge sends: b"PULSE\n"
    The bridge expects: "OK:Pulse sent"

    Args:
        port (str): Serial port name

    Returns:
        bool: True if validation passes, False otherwise
    """
    print("Validating bridge protocol compatibility...")
    print("-" * 60)

    try:
        ser = serial.Serial(port, 115200, timeout=2)
        time.sleep(0.5)

        all_passed = True

        # Test 1: Exact bridge command format
        print("\nTest 1: Bridge PULSE command format")
        print("  Command: b'PULSE\\n'")
        ser.reset_input_buffer()
        ser.reset_output_buffer()

        start_time = time.time()
        ser.write(b"PULSE\n")  # Exact format bridge uses
        time.sleep(0.02)
        response = ser.readline().decode('utf-8', errors='ignore').strip()
        elapsed_ms = (time.time() - start_time) * 1000

        print(f"  Response: '{response}'")
        print(f"  Latency: {elapsed_ms:.2f} ms")

        if response == "OK:Pulse sent":
            print("  ✓ PASS - Response format matches bridge expectations")
        else:
            print("  ✗ FAIL - Response does not match expected 'OK:Pulse sent'")
            all_passed = False

        if elapsed_ms > 1.0:
            print(f"  ⚠ WARNING - Latency {elapsed_ms:.2f} ms exceeds 1ms target")

        # Test 2: Response parsing (check for exact format)
        print("\nTest 2: Response format validation")
        if response.startswith("OK:"):
            print("  ✓ PASS - Response has 'OK:' prefix")
        else:
            print("  ✗ FAIL - Response missing 'OK:' prefix")
            all_passed = False

        if ":" in response:
            parts = response.split(":", 1)
            if len(parts) == 2:
                status, message = parts
                print(f"  Status: '{status}'")
                print(f"  Message: '{message}'")
                print("  ✓ PASS - Response is parseable")
            else:
                print("  ✗ FAIL - Response format incorrect")
                all_passed = False
        else:
            print("  ✗ FAIL - Response missing ':' separator")
            all_passed = False

        # Test 3: Case insensitivity (bridge might send lowercase)
        print("\nTest 3: Case insensitivity check")
        print("  Command: b'pulse\\n' (lowercase)")
        ser.reset_input_buffer()
        ser.write(b"pulse\n")
        time.sleep(0.02)
        response = ser.readline().decode('utf-8', errors='ignore').strip()
        print(f"  Response: '{response}'")

        if response == "OK:Pulse sent":
            print("  ✓ PASS - Accepts lowercase commands")
        else:
            print("  ✗ FAIL - Does not accept lowercase")
            all_passed = False

        # Test 4: Connection test command
        print("\nTest 4: TEST command (for connection validation)")
        print("  Command: b'TEST\\n'")
        ser.reset_input_buffer()
        ser.write(b"TEST\n")
        time.sleep(0.02)
        response = ser.readline().decode('utf-8', errors='ignore').strip()
        print(f"  Response: '{response}'")

        if response == "OK:Test successful":
            print("  ✓ PASS - TEST command supported")
        else:
            print("  ⚠ WARNING - TEST command not supported or wrong format")

        # Test 5: PULSE with duration parameter
        print("\nTest 5: PULSE with inline duration")
        print("  Command: b'PULSE 5\\n' (5ms pulse)")
        ser.reset_input_buffer()
        ser.write(b"PULSE 5\n")
        time.sleep(0.02)
        response = ser.readline().decode('utf-8', errors='ignore').strip()
        print(f"  Response: '{response}'")

        if response == "OK:Pulse sent":
            print("  ✓ PASS - PULSE with duration accepted")
        else:
            print("  ✗ FAIL - PULSE with duration not supported")
            all_passed = False

        # Test 6: TIMING command
        print("\nTest 6: TIMING command (on-device latency)")
        print("  Command: b'TIMING\\n'")
        ser.reset_input_buffer()
        ser.write(b"TIMING\n")
        time.sleep(0.02)
        response = ser.readline().decode('utf-8', errors='ignore').strip()
        print(f"  Response: '{response}'")

        if response.startswith("OK:Timing us:"):
            print("  ✓ PASS - TIMING command supported")
            # Parse the timing value
            try:
                us_str = response.split("us:")[1].split(",")[0]
                print(f"  Last pulse serial-to-GPIO latency: {us_str} µs")
            except (IndexError, ValueError):
                print("  ⚠ WARNING - Could not parse timing value")
        else:
            print("  ⚠ WARNING - TIMING command not supported (firmware < 1.4.0)")

        # Test 7: SERIAL command
        print("\nTest 7: SERIAL command (unique board ID)")
        print("  Command: b'SERIAL\\n'")
        ser.reset_input_buffer()
        ser.write(b"SERIAL\n")
        time.sleep(0.02)
        response = ser.readline().decode('utf-8', errors='ignore').strip()
        print(f"  Response: '{response}'")

        if response.startswith("OK:Serial "):
            board_serial = response.replace("OK:Serial ", "").strip()
            print(f"  ✓ PASS - Board serial: {board_serial}")
        else:
            print("  ⚠ WARNING - SERIAL command not supported (firmware < 1.4.0)")

        # Test 8: Invalid command handling
        print("\nTest 8: Error handling")
        print("  Command: b'INVALID\\n'")
        ser.reset_input_buffer()
        ser.write(b"INVALID\n")
        time.sleep(0.02)
        response = ser.readline().decode('utf-8', errors='ignore').strip()
        print(f"  Response: '{response}'")

        if response.startswith("ERROR:"):
            print("  ✓ PASS - Errors use 'ERROR:' prefix")
        else:
            print("  ⚠ WARNING - Error format may not be parseable by bridge")

        ser.close()

        return all_passed

    except serial.SerialException as e:
        print(f"\nSerial connection error: {e}")
        return False
    except Exception as e:
        print(f"\nValidation error: {e}")
        return False
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

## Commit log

2025-10-27 Update firmware to v1.1.0 with correct GPIO pin and improve repository structure
    - Update firmware to use GPIO 6 (D4 pin) for TTL output
    - Add comprehensive INSTALLATION.md with hardware setup guide
    - Reorganize repository: move Arduino/CircuitPython to examples/
    - Add testing scripts for device validation and discovery
    - Remove web interface (bridge-based communication only)
    - Update documentation with VID/PID device discovery
    - Configure USB serial number and proper USB identification
    - Add LONGPULSE command for testing visibility
    [arduino_sketch_hyperstudyttl.ino, code.py, detect_device.py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]
2025-12-20 Update firmware to v1.3.0 with OFF-to-ON pulse behavior and add FeatherWing schematic
    - Invert GPIO logic for OFF-to-ON TTL pulses (idle LOW, pulse HIGH)
    - Fix OPTOCOUPLER_WIRING.md with correct HCPL-2211 pinout (Pin 2=Anode, Pin 3=Cathode)
    - Document non-inverting totem pole output (no pull-up needed)
    - Extend LONGPULSE to 3 seconds for easier multimeter testing
    - Add hardware/ directory with FeatherWing schematic and EasyEDA design data
    - Update CLAUDE.md with corrected signal logic description
    [main.cpp]
2026-01-27 Add parametric 3D-printable case design for HyperStudy TTL FeatherWing
    Case features:
    - Two-shell design (bottom + top) with M2 screw assembly
    - Hex nut pockets on bottom shell exterior for captive nuts
    - PCB standoffs aligned with FeatherWing mounting holes
    - USB-C and BNC connector cutouts with proper offsets
    - Rubber feet recesses centered over nut pockets
    - PCB support rails on USB/Feather section (avoids FeatherWing components)
    - BNC-side support ribs connected to wall and ceiling
    Key design decisions:
    - 4mm floor thickness to accommodate 2mm nut pockets
    - 1.5mm PCB clearance for 1.2mm support rails (0.3mm gap)
    - Rails offset by PCB thickness + 0.5mm for flush/inset mounting
    - Print or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
    [hyperstudy-ttl-case.3mf, hyperstudy-ttl-case.scad, hyperstudy-ttl-case.stl]
2026-01-27 Revise case design based on print test findings
    - Widen PCB support rails from 1.2mm to 4mm and extend to ceiling
    (matching BNC corner posts for consistent hold-down pressure)
    - Increase screw/standoff hole diameters from 2.2mm to 2.6mm for
    FDM shrinkage tolerance
    - Reduce feather_extension from 5mm to 3.5mm to bring USB wall closer
    - Increase floor thickness from 4mm to 5mm for better bridging
    - Increase nut pocket depth (2.0→2.5mm) and width (4.5→5.0mm) for
    better FDM print quality and nut capture
    - Remove rubber foot recesses to eliminate 10mm bridging problem
    that caused poor nut pocket print quality
    - Specify M2x30mm screws for assembly
    [hyperstudy-ttl-case.scad]
2026-01-30 Add counterbore for M2 pan head screws in top shell
    Replace shallow conical countersink with cylindrical counterbore
    (2.5mm deep, 4.5mm diameter) to properly seat pan head screws
    flush with the case surface and improve screw reach to nuts.
    [hyperstudy-ttl-case.scad]
2026-02-01 Fix standoff height and add interlocking lip to case design
    - Fix standoff height calculation: remove erroneous +1.3mm offset that
    caused PCB to sit above shell interface, creating gap between shells
    - Add interlocking lip (tongue-and-groove) on three sides of bottom
    shell for lateral alignment (excludes BNC end for connector clearance)
    - Lip parameters: 1.5mm height, 1.5mm thickness, 0.3mm clearance
    - Height chosen to clear top shell PCB support ribs (0.6mm clearance)
    [hyperstudy-ttl-case.scad]
2026-02-01 Update case documentation for current design
    - Update hardware requirements: M2x35mm screws + M2 hex nuts
    - Add assembly steps for hex nut installation and screw path
    - Document interlocking lip feature and PCB support ribs
    - Update dimensions to match current SCAD parameters
    - Add print orientation instructions (flip top shell)
    - Update troubleshooting for lip clearance and standoff issues
    - Remove references to unused logo/icon feature
2026-02-06 Thicken both shells to flush M2x35mm screws and disable interlocking lip
    Increase floor_thickness 6→7mm and ceiling_thickness 3.5→4.5mm so
    M2x35mm screws recess 0.7mm into nut pocket instead of protruding
    ~1.3mm past the bottom surface. Also disable interlocking lip due
    to FDM printing geometry issues.
    [hyperstudy-ttl-case.scad]
2026-02-17 Firmware v1.4.0: configurable pulse duration, on-device timing, unique serial numbers
    - Remove delay(1) polling bottleneck for sub-100μs on-device latency
    - Add PULSE <ms> inline duration parameter (parsed after GPIO toggle)
    - Add SETDURATION command to set default pulse duration at runtime
    - Add TIMING command to query serial-to-GPIO latency in microseconds
    - Add SERIAL command to report unique board ID from flash chip
    - Remove hardcoded USB_SERIAL so TinyUSB auto-generates from flash ID
    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
2026-02-17 Fix sync-docs workflow: use env vars, temp file, and Contents API
    Align with the working bridge workflow pattern:
    - Pass release body via env var instead of inline expression
    - Write release entry to temp file instead of shell variable
    - Use awk getline from file for reliable multiline insertion
    - Push via GitHub Contents API instead of git push
    - Add persist-credentials: false on checkout
